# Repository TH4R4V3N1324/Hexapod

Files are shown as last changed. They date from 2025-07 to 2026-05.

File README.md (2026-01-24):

# Hexapod

This repository contains the complete design, control software and documentation for a six-legged walking robot (hexapod). The project combines robotics, kinematics, embedded systems, and motion planning to create a stable and adaptable walking platform.

---

## Table of Contents

- [About](#about)
- [Features](#features)
- [Installation](#installation)
  - [Hexapod](#hexapod)
  - [Receiver & Controller](#receiver--controller)
- [Usage](#usage)

---

## About

This project was developed to address the growing complexity in robotic control systems, where tightly coupled codebases often hinder scalability, debugging, and long-term maintainability. It is designed for developers, researchers, or engineers working with robotic platforms or automation systems who require a clean, extensible control framework that’s easy to understand and build upon.

The primary goal of the project was to emphasize modularity, ensuring that each component of the control software is clearly separated by function and responsibility. This modular design allows developers to quickly comprehend the structure of the system, make targeted changes without unintended side effects, and expand the system by adding new features or improving existing ones without rewriting the entire codebase.

To achieve this, the software is structured around a set of well-defined classes, each serving a distinct role:

- DataPacket Class: Acts as a container for incoming or outgoing data, ensuring that all communication between system components remains consistent, structured, and easily interpretable.

- Calculate Class: Handles all mathematical and logical computations required by the system, such as sensor data interpretation, decision-making algorithms, or movement planning.

- Move Class: Directly interfaces with the actuators or motors, translating high-level commands into specific movement instructions. It abstracts the hardware layer, allowing for easier adaptation across different platforms.

- Animation Class: Manages co-ordination of legs using the various gaits and modes to create walking and animation.

---

## Features

- 3 DOF per leg
- Inverse Kinematic engine for stable gait control
- Multiple gait patterns: tripod, ripple, wave
- Multiple control modes: normal, strafe, tilt
- Real-time control via Pimironi Servo2040
- Wireless control using custom controller and EspNOW protocol
- STL files for 3D-printing mechanical components

---

## Installation

Describe how to get your project running locally. Include prerequisites, dependencies, and step-by-step instructions.

Clone the repository into the desired location using the git bash terminal.
```bash
git clone https://github.com/TH4R4V3N1324/Hexapod.git
```

### Hexapod
Before getting started, make sure you have the following installed:

#### Prerequisites
- [Visual Studio Code](https://code.visualstudio.com/)
- [Pico SDK and cmake toolchain](https://github.com/raspberrypi/pico-sdk)
- [Raspberry Pi Pico VSCode Extension](https://marketplace.visualstudio.com/items?itemName=raspberry-pi.raspberry-pi-pico)

#### Dependencies
- [Pimironi pico sdk](https://github.com/pimoroni/pimoroni-pico.git)

Using the Raspberry Pi Pico VSCode extension, import the Hexapod sub-folder by selecting it in the **Location** tab, enabling **CMake-Tools** and clicking **Import**. 



A selection box will appear at the top of the screen. From the list, choose the appropriate Pico compiler.



Once imported, you can build the project by selecting **Compile Project** from the Pico extension commands. This will generate a .uf2 firmware file inside the build directory.

To flash the firmware to the Pimoroni Servo 2040, put the board into BOOTSEL mode (by holding the BOOT button and pressing RESET), then copy the .uf2 file to the mounted USB storage.

Alternatively, you can enter BOOTSEL mode first, then simply use the **Run Project** command. This will automatically build and flash the firmware to the board, no manual file transfer required.



### Receiver & Controller

#### Prerequisites
- [PlatformIO VSCode Extension](https://marketplace.visualstudio.com/items?itemName=platformio.platformio-ide)

#### Dependencies
- [u8g2 library](https://github.com/olikraus/u8g2.git)

Using the PlatformIO extension in VS Code, select the **Open** option under the **Quick Access** panel to launch the PlatformIO Home page. From there, click **Open Project** and navigate to the appropriate sub-folder to import your project.



To build or upload the project to your ESP32 board, use the **Build** or **Upload** options available under the **Project Tasks** panel in the PlatformIO extension.



---

## Usage

Explain how to use the project. Provide code snippets, screenshots, or examples as helpful.

# Ideas:
# Use ROS2 for control



## Package Structure

### 1. hexapod_description (URDF/Configuration)

- Robot URDF model with leg geometry
- Joint limits and physical parameters
- Launch files for simulation and hardware

### 2. hexapod_hardware_interface (Hardware Layer)

#### Servo Controller Node: Interfaces with PCA9685 or direct PWM

- Subscribes to: /joint_commands (JointState)
- Publishes: /joint_states (JointState with feedback)
- Service: /emergency_stop

#### Sensor Manager Node: Aggregates all sensor data

- Publishes: /imu/data (sensor_msgs/Imu)
- Publishes: /power/status (custom PowerStatus msg)
- Publishes: /leg_contact (custom LegContactArray msg)

### 3. hexapod_kinematics (Computation Layer)

#### IK/FK Solver Node: Your Calculate class logic
- Service: /ik_solve (Vector3 → JointAngles)
- Service: /fk_solve (JointAngles → Vector3)
- Subscribes to: /joint_states (JointState)
- Publishes: /leg_poses (geometry_msgs/PoseArray

### 4. hexapod_gait_controller (Motion Planning)

#### Gait Generator Node: Your Animation/Move logic

- Subscribes to: /cmd_vel (Twist for velocity commands)
- Subscribes to: /gait_mode (String: tripod/ripple/wave)
- Publishes: /leg_trajectories (trajectory_msgs/JointTrajectory)
- Action Server: /execute_gait for complex movements

### 5. hexapod_control (High-Level Control)

#### Behavior Manager Node: State machine (Normal/Strafe/Tilt/Config)

- Subscribes to: /mode_command (custom ModeCommand)
- Subscribes to: /joystick (sensor_msgs/Joy)
- Publishes: /cmd_vel (Twist)
- Service: /set_height, /home_stance

#### Config Manager Node: Servo offset calibration

- Reads/writes to parameter server
- Service: /save_config, /load_config

### 6. hexapod_teleop (User Interface)

#### Joystick Node: Replaces your ESP-NOW controller

- Uses joy_node from ROS2
- Publishes: /joystick (sensor_msgs/Joy)

#### Web Interface Node: Optional dashboard

- rqt plugins or custom web interface
- Monitor battery, IMU, leg contact

# Use Isaac sim for simulation

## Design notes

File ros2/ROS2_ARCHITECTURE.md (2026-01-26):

# Hexapod ROS2 Architecture

This document describes the ROS2 package architecture for the Hexapod robot, designed to work with an ESP32-S3 as a dumb I/O board.

## Table of Contents

- [System Overview](#system-overview)
- [Package Summary](#package-summary)
- [1. hexapod\_msgs](#1-hexapod_msgs)
- [2. hexapod\_description](#2-hexapod_description)
- [3. hexapod\_hardware\_interface](#3-hexapod_hardware_interface)
- [4. hexapod\_gait\_controller](#4-hexapod_gait_controller)
- [5. hexapod\_control](#5-hexapod_control)
- [6. hexapod\_teleop](#6-hexapod_teleop)
- [Data Flow](#data-flow)
- [Topic Reference](#topic-reference)
- [Service Reference](#service-reference)
- [Launch Files](#launch-files)

---

## System Overview

```
┌─────────────────────────────────────────────────────────────────────────────────────┐
│                                    ROS2 System                                       │
│                                                                                      │
│  ┌────────────────┐     ┌────────────────────┐     ┌──────────────────────────────┐ │
│  │ hexapod_teleop │────▶│  hexapod_control   │────▶│  hexapod_gait_controller     │ │
│  │  (user input)  │     │  (behavior/state)  │     │  (motion + IK library)       │ │
│  └────────────────┘     └────────────────────┘     └──────────────┬───────────────┘ │
│                                                                    │                 │
│                                                                    ▼                 │
│  ┌────────────────────────────────────────────────────────────────────────────────┐ │
│  │                      hexapod_hardware_interface                                 │ │
│  │                      (ESP32 serial bridge)                                      │ │
│  └────────────────────────────────────────────────────────────────┬───────────────┘ │
│                                                                    │                 │
│  ┌────────────────┐                                               │                 │
│  │hexapod_descrip-│  URDF/meshes/configs used by all packages     │                 │
│  │tion            │                                               │                 │
│  └────────────────┘                                               │                 │
└───────────────────────────────────────────────────────────────────┼─────────────────┘
                                                                    │ Serial
                                                                    ▼
                                                        ┌───────────────────────┐
                                                        │   ESP32-S3 (Dumb I/O) │
                                                        │   PWM + Sensors +     │
                                                        │   ESP-NOW Relay       │
                                                        └───────────────────────┘
```

### Design Philosophy

- **ESP32 as Dumb I/O**: The ESP32-S3 main board only handles:
  - Receiving joint angles → driving servo PWM
  - Reading sensors → sending to ROS2
  - Relaying ESP-NOW controller data → sending to ROS2
- **ROS2 as Brain**: All intelligence (gait generation, inverse kinematics, behavior control) runs on the companion computer
- **ESP-NOW Controller**: A separate ESP32 controller connects wirelessly to the main board and provides joystick input

---

## Package Summary

| Package | Purpose | Key Components |
|---|---|---|
| `hexapod_msgs` | Custom message/service/action definitions | ControllerInput, PowerStatus, LegContactArray |
| `hexapod_description` | Robot model and configuration | URDF, meshes, parameter files |
| `hexapod_hardware_interface` | ESP32 serial communication | esp32_bridge_node |
| `hexapod_gait_controller` | Motion planning + kinematics | gait_controller_node, kinematics library |
| `hexapod_control` | Behavior and state management | behavior_manager_node, config_manager_node |
| `hexapod_teleop` | Alternative user input methods | joy_teleop_node, keyboard_teleop_node |

---

## 1. hexapod_msgs

**Purpose**: Centralized custom message, service, and action definitions. All other packages depend on this.

### Messages

#### ControllerRaw.msg

Unified controller input that supports multiple input sources (ESP-NOW controller, virtual joystick, keyboard, etc.).

```
# Header with timestamp
builtin_interfaces/Time stamp

# Controller axes (normalized -1.0 to 1.0)
# Standard mapping: [left_x, left_y, right_x, right_y, ...]
# Can be extended for additional axes (triggers, etc.)
float32[] axes

# Discrete command (see Command enum below)
uint16 command_id

# Optional parameters for commands
# e.g., [gait_id], [leg_id, joint_id, offset], [height_mm]
float32[] arguments

# Input source identifier
uint8 source_id

# Source ID constants
uint8 SOURCE_ESPNOW = 0      # Physical ESP-NOW controller
uint8 SOURCE_VIRTUAL_JOY = 1 # Virtual joystick (GUI)
uint8 SOURCE_KEYBOARD = 2    # Keyboard teleop
uint8 SOURCE_GAMEPAD = 3     # USB/Bluetooth gamepad
uint8 SOURCE_AUTONOMY = 4    # Autonomous navigation stack

# Command ID constants (matches embedded Command enum)
uint16 CMD_NONE = 0
uint16 CMD_SET_GAIT = 1
uint16 CMD_SET_MODE = 2
uint16 CMD_SET_CONFIG = 3
uint16 CMD_HOME_STANCE = 4
uint16 CMD_REQUEST_CONFIG = 5
uint16 CMD_SET_HEIGHT = 6
uint16 CMD_EMERGENCY_STOP = 7
```

**Axis Mapping Convention:**

| Index | Axis | Range | Description |
|---|---|---|---|
| 0 | `left_x` | -1.0 to 1.0 | Left stick horizontal (strafe/rotate) |
| 1 | `left_y` | -1.0 to 1.0 | Left stick vertical (forward/back) |
| 2 | `right_x` | -1.0 to 1.0 | Right stick horizontal (rotate/strafe) |
| 3 | `right_y` | -1.0 to 1.0 | Right stick vertical (height adjust) |

**Why this design:**
- **Normalized floats**: Consistent across all input devices (ESP-NOW sends int16 which gets normalized)
- **Extensible axes**: Support for triggers, extra buttons as analog values
- **Source tracking**: Know which controller sent the command for priority/conflict resolution
- **Flexible arguments**: Commands like `CMD_SET_CONFIG` need multiple parameters

#### LegContactArray.msg

Ground contact state for each leg (1-6). Used for adaptive gait and terrain sensing.

```
std_msgs/Header header
bool[6] contacts
```

#### PowerStatus.msg

Power monitoring from INA260. For battery management and safety shutdowns.

```
float32 voltage
float32 current
float32 power
float32 battery_percent
bool low_battery_warning
```

#### HexapodState.msg

Overall robot state broadcast for monitoring/logging.

```
uint8 mode
uint8 gait
float32 body_height
int8 gait_phase
bool is_moving
bool is_stable
```

#### LegCommand.msg

Single leg command with both Cartesian position and joint angles.

```
uint8 leg_id
geometry_msgs/Point position
float64[3] joint_angles
```

### Services

#### SetGait.srv

Change walking gait pattern.

```
# Request
uint8 gait  # 0=tripod, 1=ripple, 2=wave
---
# Response
bool success
string message
```

#### SetMode.srv

Change behavior mode.

```
# Request
uint8 mode  # 0=normal, 1=strafe, 2=tilt, 3=config
---
# Response
bool success
string message
```

#### SetHeight.srv

Adjust body height (clamped to valid range).

```
# Request
float32 height_mm
---
# Response
bool success
float32 actual_height
```

#### GetLegConfig.srv

Retrieve servo calibration offsets.

```
# Request
uint8 leg_id
---
# Response
int16[3] offsets  # coxa, femur, tibia
```

#### SetLegConfig.srv

Set servo calibration offset.

```
# Request
uint8 leg_id
uint8 joint_id
int16 offset
---
# Response
bool success
```

#### SaveConfig.srv

Persist calibration to file.

```
# Request
---
# Response
bool success
string filepath
```

#### EmergencyStop.srv

Disable all servos immediately.

```
# Request
bool stop
---
# Response
bool success
```

### Actions

#### HomeStance.action

Return all legs to home position smoothly.

```
# Goal
---
# Feedback
float32 progress
uint8 current_leg
---
# Result
bool success
float32 duration
```

#### ExecuteAnimation.action

Run predefined animations (startup, shutdown, wave).

```
# Goal
string animation_name
float32 speed
---
# Feedback
float32 progress
uint8 phase
---
# Result
bool success
```

---

## 2. hexapod_description

**Purpose**: Contains the robot's physical description (URDF), visual meshes, and default configuration parameters. This is a **data-only package** with no nodes.

### Directory Structure

```
hexapod_description/
├── urdf/
│   ├── hexapod.urdf.xacro          # Main robot description
│   ├── leg.urdf.xacro              # Single leg macro (reused 6x)
│   └── materials.xacro             # Colors/materials
├── meshes/
│   ├── body.stl
│   ├── coxa.stl
│   ├── femur.stl
│   └── tibia.stl
├── config/
│   ├── hexapod_params.yaml         # Default parameters
│   ├── servo_calibration.yaml      # Joint offsets
│   ├── gait_configs.yaml           # Gait phase patterns
│   └── joint_limits.yaml           # Min/max angles per joint
├── launch/
│   ├── display.launch.py           # RViz visualization
│   ├── hardware.launch.py          # Real robot
│   └── simulation.launch.py        # Gazebo
└── rviz/
    └── hexapod.rviz                # RViz config
```

### Configuration Files

#### hexapod_params.yaml

```yaml
hexapod:
  geometry:
    coxa_length: 50.5      # mm
    femur_length: 90.0     # mm
    tibia_length: 150.35   # mm
    body_radius: 100.0     # mm - distance from center to coxa
  
  legs:
    # Leg mounting angles and mirror flags
    leg_1: { angle: -45.0, mirrored: false, home: [0, 150, -120] }
    leg_2: { angle: 0.0, mirrored: false, home: [0, 150, -120] }
    leg_3: { angle: 45.0, mirrored: false, home: [0, 150, -120] }
    leg_4: { angle: 135.0, mirrored: true, home: [0, 150, -120] }
    leg_5: { angle: 180.0, mirrored: true, home: [0, 150, -120] }
    leg_6: { angle: -135.0, mirrored: true, home: [0, 150, -120] }
  
  motion:
    default_height: 120    # mm
    min_height: 60
    max_height: 180
    step_height: 40        # mm - lift height during swing
    step_resolution: 50    # trajectory points per step
```

#### gait_configs.yaml

```yaml
gaits:
  tripod:
    phase_groups: [[1, 3, 5], [2, 4, 6]]    # Two alternating groups
    duty_cycle: 0.5                          # 50% stance, 50% swing
  ripple:
    phase_groups: [[1, 4], [2, 5], [3, 6]]  # Three groups
    duty_cycle: 0.67
  wave:
    phase_groups: [[1], [2], [3], [4], [5], [6]]  # One leg at a time
    duty_cycle: 0.83
```

### Data Flow

- **To**: All other packages load URDF and configs via `xacro` and ROS2 parameter server
- **Used by**: `robot_state_publisher` for TF, RViz for visualization, Gazebo for simulation

---

## 3. hexapod_hardware_interface

**Purpose**: Bridge between ROS2 and ESP32. Handles serial communication, sensor data ingestion, and joint command transmission. The ESP32 is treated as a dumb I/O device.

### Nodes

#### esp32_bridge_node

Bidirectional serial protocol handler.

**Implementation Details**:
- Uses serial port (e.g., `/dev/ttyUSB0` at 115200 baud)
- Binary protocol with checksums for reliability
- Runs at 100Hz to match ESP32 sensor rate

**Subscribes to**:

| Topic | Type | Source | Purpose |
|---|---|---|---|
| `/hexapod/joint_commands` | `sensor_msgs/JointState` | `gait_controller` | 18 joint angles to send to ESP32 for PWM |

**Publishes**:

| Topic | Type | Destination | Purpose |
|---|---|---|---|
| `/hexapod/controller_input` | `hexapod_msgs/ControllerInput` | `hexapod_control` | Raw joystick data relayed from ESP-NOW controller |
| `/hexapod/joint_states` | `sensor_msgs/JointState` | `robot_state_publisher`, RViz | Current joint positions |
| `/imu/data` | `sensor_msgs/Imu` | `hexapod_control` | Pitch/roll from BMI330 |
| `/hexapod/power` | `hexapod_msgs/PowerStatus` | `hexapod_control`, diagnostics | Voltage/current from INA260 |
| `/hexapod/leg_contacts` | `hexapod_msgs/LegContactArray` | `gait_controller` | Ground contact switches |

**Services**:

| Service | Purpose |
|---|---|
| `/hexapod/emergency_stop` | Sends stop command to ESP32, disables all servo PWM |

**Parameters**:

```yaml
esp32_bridge:
  ros__parameters:
    serial_port: "/dev/ttyUSB0"
    baud_rate: 115200
    publish_rate: 100.0        # Hz
    command_timeout: 0.1       # seconds before servo disable
    reconnect_interval: 2.0    # seconds between reconnection attempts
```

### Serial Protocol

**ROS2 → ESP32 (Joint Commands)**:
```
┌──────┬────────┬────────────────────┬──────────┐
│ 0xAA │ Length │ float32[18] angles │ Checksum │
└──────┴────────┴────────────────────┴──────────┘
```

**ESP32 → ROS2 (Sensor Data)**:
```
┌──────┬────────┬───────────────────────────────────────────────┬──────────┐
│ 0xBB │ Length │ pitch, roll, current, voltage, contacts[6],   │ Checksum │
│      │        │ joy_lx, joy_ly, joy_rx, joy_ry, cmd, args[3]  │          │
└──────┴────────┴───────────────────────────────────────────────┴──────────┘
```

---

## 4. hexapod_gait_controller

**Purpose**: Combines gait pattern generation and inverse kinematics into a single package. The embedded `Animation`, `Move`, and `Calculate` classes are ported here. Kinematics is implemented as a **library within this package** (not a separate node).

### Package Structure

```
hexapod_gait_controller/
├── include/hexapod_gait_controller/
│   ├── kinematics.hpp              # IK/FK calculations
│   ├── trajectory_generator.hpp    # Swing/stance curve generation
│   ├── gait_patterns.hpp           # Tripod/ripple/wave configurations
│   └── leg_controller.hpp          # Per-leg state management
├── src/
│   ├── kinematics.cpp
│   ├── trajectory_generator.cpp
│   ├── gait_patterns.cpp
│   ├── leg_controller.cpp
│   └── gait_controller_node.cpp    # Main node
├── launch/
│   └── gait_controller.launch.py
└── config/
    └── gait_params.yaml
```

### Kinematics Library

Provides IK/FK functions used internally. Not exposed as services (faster, no RPC overhead).

```cpp
namespace hexapod_kinematics {

struct JointAngles {
    double coxa, femur, tibia;
};

struct LegConfig {
    double rotation_angle;    // Leg mounting angle
    bool is_mirrored;         // Left vs right side
    Eigen::Vector3d offset;   // Translation from body center
};

class Kinematics {
public:
    Kinematics(double coxa_len, double femur_len, double tibia_len);
    
    // Inverse kinematics: foot position → joint angles
    // Returns false if position unreachable
    bool solveIK(const Eigen::Vector3d& foot_pos, int leg_id, JointAngles& angles);
    
    // Forward kinematics: joint angles → foot position
    Eigen::Vector3d solveFK(const JointAngles& angles, int leg_id);
    
    // Transform between body frame and leg frame
    Eigen::Vector3d bodyToLegFrame(const Eigen::Vector3d& pos, int leg_id);
    Eigen::Vector3d legToBodyFrame(const Eigen::Vector3d& pos, int leg_id);
    
    void setLegConfig(int leg_id, const LegConfig& config);

private:
    double coxa_length_, femur_length_, tibia_length_;
    std::array<LegConfig, 6> leg_configs_;
};

} // namespace hexapod_kinematics
```

### Nodes

#### gait_controller_node

Main motion planning node. Generates leg trajectories based on velocity commands, runs IK, outputs joint angles at 100Hz.

**Key Responsibilities**:
1. Receive velocity commands (`/cmd_vel`)
2. Generate foot trajectories for current gait pattern
3. Run IK to convert foot positions to joint angles
4. Publish joint commands at high rate

**Subscribes to**:

| Topic | Type | Source | Why Needed |
|---|---|---|---|
| `/hexapod/cmd_vel` | `geometry_msgs/Twist` | `hexapod_control` | Linear.x = forward, linear.y = strafe, angular.z = rotation |
| `/hexapod/leg_contacts` | `hexapod_msgs/LegContactArray` | `hardware_interface` | Detect early ground contact for adaptive stepping |
| `/imu/data` | `sensor_msgs/Imu` | `hardware_interface` | Body orientation for leveling on slopes |

**Publishes**:

| Topic | Type | Destination | Content |
|---|---|---|---|
| `/hexapod/joint_commands` | `sensor_msgs/JointState` | `hardware_interface` | 18 joint angles at 100Hz |
| `/hexapod/leg_poses` | `geometry_msgs/PoseArray` | RViz, debugging | Current foot positions in body frame |
| `/hexapod/state` | `hexapod_msgs/HexapodState` | `hexapod_control`, monitoring | Current gait, phase, stability status |

**Services**:

| Service | Purpose |
|---|---|
| `/hexapod/set_gait` | Switch gait pattern (tripod/ripple/wave) |
| `/hexapod/set_height` | Adjust body height with smooth interpolation |

**Action Servers**:

| Action | Purpose |
|---|---|
| `/hexapod/home_stance` | Return all legs to home position with progress feedback |
| `/hexapod/execute_animation` | Run predefined sequences (startup, shutdown, wave) |

**Parameters**:

```yaml
gait_controller:
  ros__parameters:
    # Geometry (loaded from hexapod_description)
    coxa_length: 50.5
    femur_length: 90.0
    tibia_length: 150.35
    
    # Motion
    control_rate: 100.0         # Hz
    default_gait: "tripod"
    step_height: 40.0           # mm
    trajectory_resolution: 50   # points per swing phase
    
    # Body
    default_height: 120.0       # mm
    
    # Stability
    enable_body_leveling: true
    max_level_correction: 20.0  # mm max leg adjustment
    
    # Adaptive gait
    enable_contact_adaptation: true
```

**Internal State Machine**:

```
┌──────────┐    cmd_vel    ┌──────────┐   all legs    ┌──────────┐
│   IDLE   │──────────────▶│ WALKING  │───grounded───▶│   IDLE   │
└──────────┘   (non-zero)  └────┬─────┘   (zero vel)  └──────────┘
      │                         │
      │                         │ home_stance action
      ▼                         ▼
┌──────────┐              ┌──────────┐
│ STARTUP  │              │  HOMING  │
└──────────┘              └──────────┘
```

---

## 5. hexapod_control

**Purpose**: High-level behavior control. Manages operating modes (normal/strafe/tilt/config), interprets controller input, and coordinates system-wide state. This is the embedded `StateFSM` and `CommandFSM` logic.

### Nodes

#### behavior_manager_node

State machine that interprets user input and manages operating modes.

**Subscribes to**:

| Topic | Type | Source | Why Needed |
|---|---|---|---|
| `/hexapod/controller_input` | `hexapod_msgs/ControllerInput` | `hardware_interface` | Raw joystick data from ESP-NOW controller |
| `/hexapod/state` | `hexapod_msgs/HexapodState` | `gait_controller` | Current robot state for decision making |
| `/imu/data` | `sensor_msgs/Imu` | `hardware_interface` | Body orientation for tilt mode |
| `/hexapod/power` | `hexapod_msgs/PowerStatus` | `hardware_interface` | Battery level for warnings/shutdown |

**Publishes**:

| Topic | Type | Destination | Content |
|---|---|---|---|
| `/hexapod/cmd_vel` | `geometry_msgs/Twist` | `gait_controller` | Processed velocity command based on mode |
| `/hexapod/mode` | `std_msgs/UInt8` | Monitoring, UI | Current mode (0-3) |

**Services Called**:

| Service | When Called |
|---|---|
| `/hexapod/set_gait` | When `command == CMD_SET_GAIT` received |
| `/hexapod/set_mode` | When `command == CMD_SET_MODE` received |
| `/hexapod/home_stance` | When `command == CMD_HOME_STANCE` received |
| `/hexapod/emergency_stop` | When battery critical or error detected |

**Mode Behaviors**:

| Mode | Joystick Mapping | Special Behavior |
|---|---|---|
| **NORMAL** | Left stick: forward/rotate, Right stick: height | Standard walking |
| **STRAFE** | Left stick: forward/strafe, Right stick: rotate/height | Omnidirectional movement |
| **TILT** | Left stick: pitch body, Right stick: roll body | IMU-assisted body tilting |
| **CONFIG** | Left stick: select leg/joint, Right stick: adjust offset | Servo calibration mode |

**Command Handling** (from embedded `CommandFSM`):

```cpp
void handleCommand(const ControllerInput& input) {
    switch (input.command) {
        case CMD_SET_GAIT:
            callService("/hexapod/set_gait", input.command_args[0]);
            break;
        case CMD_SET_MODE:
            current_mode_ = input.command_args[0];
            break;
        case CMD_HOME_STANCE:
            callAction("/hexapod/home_stance");
            break;
        case CMD_SET_CONFIG:
            callService("/hexapod/set_leg_config", 
                input.command_args[0],  // leg
                input.command_args[1],  // joint  
                input.command_args[2]); // offset
            break;
    }
}
```

#### config_manager_node

Manages servo calibration offsets. Replaces the embedded `ConfigManager` class.

**Services**:

| Service | Purpose |
|---|---|
| `/hexapod/get_leg_config` | Retrieve offsets for a leg |
| `/hexapod/set_leg_config` | Set offset for a specific joint |
| `/hexapod/save_config` | Write current offsets to YAML file |
| `/hexapod/load_config` | Load offsets from YAML file |

**Publishes**:

| Topic | Type | Purpose |
|---|---|---|
| `/hexapod/joint_offsets` | `sensor_msgs/JointState` | Current calibration offsets |

**Data Storage**:
- Offsets stored in `hexapod_description/config/servo_calibration.yaml`
- Loaded at startup, saved on request

---

## 6. hexapod_teleop

**Purpose**: Alternative input methods beyond the ESP-NOW controller. Useful for development, testing, and when ESP32 controller isn't available.

### Nodes

#### joy_teleop_node

Convert standard gamepad to controller input format.

**Subscribes to**:

| Topic | Type | Source |
|---|---|---|
| `/joy` | `sensor_msgs/Joy` | `joy` package (gamepad driver) |

**Publishes**:

| Topic | Type | Purpose |
|---|---|---|
| `/hexapod/cmd_vel` | `geometry_msgs/Twist` | Direct velocity commands |

**Parameters**:

```yaml
joy_teleop:
  ros__parameters:
    # Axis mappings (for Xbox controller)
    axis_linear_x: 1      # Left stick Y
    axis_linear_y: 0      # Left stick X
    axis_angular_z: 3     # Right stick X
    axis_height: 4        # Right stick Y
    
    # Button mappings
    btn_gait_cycle: 0     # A button
    btn_mode_cycle: 1     # B button
    btn_home: 2           # X button
    btn_emergency: 7      # Start button
    
    # Scaling
    max_linear: 100.0     # mm/s
    max_angular: 0.5      # rad/s
    deadzone: 0.1
```

#### keyboard_teleop_node (Optional)

Simple keyboard control for testing.

**Key Mappings**:
- WASD: Move forward/strafe
- QE: Rotate
- RF: Height up/down
- 1/2/3: Select gait
- Space: Home stance

---

## Data Flow

```
┌─────────────────────────────────────────────────────────────────────────────────────┐
│                                                                                      │
│   ESP32 Controller ──ESP-NOW──▶ ESP32 Main Board                                    │
│                                      │                                               │
│                                      │ Serial @ 100Hz                               │
│                                      ▼                                               │
│   ┌─────────────────────────────────────────────────────────────────────────────┐   │
│   │                        esp32_bridge_node                                     │   │
│   │  OUT: /controller_input, /imu/data, /power, /leg_contacts, /joint_states    │   │
│   │  IN:  /joint_commands                                                        │   │
│   └───────┬────────────┬────────────┬────────────┬───────────────────────────────┘   │
│           │            │            │            │                                   │
│           ▼            ▼            ▼            │                                   │
│   /controller_input  /imu/data   /power     /leg_contacts                           │
│           │            │   │        │            │                                   │
│           ▼            │   │        ▼            │                                   │
│   ┌──────────────────┐ │   │  ┌──────────┐       │                                   │
│   │behavior_manager  │◀┘   │  │Diagnostics│      │                                   │
│   │                  │     │  │Low battery│      │                                   │
│   │ Mode: NORMAL     │     │  └──────────┘       │                                   │
│   │ CMD handling     │     │                     │                                   │
│   └────────┬─────────┘     │                     │                                   │
│            │               │                     │                                   │
│            ▼               │                     │                                   │
│      /cmd_vel              │                     │                                   │
│            │               │                     │                                   │
│            ▼               ▼                     ▼                                   │
│   ┌────────────────────────────────────────────────────────────────────────────┐    │
│   │                      gait_controller_node                                   │    │
│   │                                                                             │    │
│   │  ┌──────────────┐   ┌──────────────┐   ┌─────────────────┐                 │    │
│   │  │Gait Generator│──▶│Trajectory Gen│──▶│IK (kinematics)  │                 │    │
│   │  │tripod/ripple │   │swing/stance  │   │pos → angles     │                 │    │
│   │  └──────────────┘   └──────────────┘   └────────┬────────┘                 │    │
│   │                                                  │                          │    │
│   └──────────────────────────────────────────────────┼──────────────────────────┘    │
│                                                      │                               │
│                                                      ▼                               │
│                                              /joint_commands                         │
│                                                      │                               │
│                                                      ▼                               │
│   ┌─────────────────────────────────────────────────────────────────────────────┐   │
│   │                        esp32_bridge_node                                     │   │
│   └─────────────────────────────────────────────────────────────────────────────┘   │
│                                      │                                               │
│                                      │ Serial                                        │
│                                      ▼                                               │
│                              ESP32 Main Board                                        │
│                                      │                                               │
│                                      ▼ PWM                                           │
│                                  [18 Servos]                                         │
│                                                                                      │
└─────────────────────────────────────────────────────────────────────────────────────┘
```

---

## Topic Reference

| Topic | Type | Publisher | Subscriber(s) | Rate |
|---|---|---|---|---|
| `/hexapod/controller_input` | `ControllerInput` | `esp32_bridge` | `behavior_manager` | 50Hz |
| `/hexapod/joint_commands` | `JointState` | `gait_controller` | `esp32_bridge` | 100Hz |
| `/hexapod/joint_states` | `JointState` | `esp32_bridge` | `robot_state_publisher` | 100Hz |
| `/hexapod/cmd_vel` | `Twist` | `behavior_manager` | `gait_controller` | 50Hz |
| `/hexapod/leg_contacts` | `LegContactArray` | `esp32_bridge` | `gait_controller` | 100Hz |
| `/hexapod/power` | `PowerStatus` | `esp32_bridge` | `behavior_manager` | 10Hz |
| `/hexapod/state` | `HexapodState` | `gait_controller` | `behavior_manager` | 20Hz |
| `/hexapod/leg_poses` | `PoseArray` | `gait_controller` | RViz | 20Hz |
| `/hexapod/mode` | `UInt8` | `behavior_manager` | Monitoring | On change |
| `/imu/data` | `Imu` | `esp32_bridge` | `gait_controller`, `behavior_manager` | 100Hz |
| `/tf` | `TFMessage` | `robot_state_publisher` | RViz, others | 100Hz |

---

## Service Reference

| Service | Package | Purpose |
|---|---|---|
| `/hexapod/set_gait` | `gait_controller` | Change gait pattern |
| `/hexapod/set_mode` | `control` | Change behavior mode |
| `/hexapod/set_height` | `gait_controller` | Adjust body height |
| `/hexapod/get_leg_config` | `control` | Get servo offsets |
| `/hexapod/set_leg_config` | `control` | Set servo offset |
| `/hexapod/save_config` | `control` | Save calibration |
| `/hexapod/load_config` | `control` | Load calibration |
| `/hexapod/emergency_stop` | `hardware_interface` | Disable servos |

---

## Launch Files

### hexapod_bringup/launch/hexapod.launch.py

```python
from launch import LaunchDescription
from launch_ros.actions import Node
from launch.actions import IncludeLaunchDescription

def generate_launch_description():
    return LaunchDescription([
        # Robot description & TF
        IncludeLaunchDescription(
            'hexapod_description/launch/robot_state_publisher.launch.py'
        ),
        
        # Hardware interface
        Node(
            package='hexapod_hardware_interface',
            executable='esp32_bridge_node',
            parameters=['config/esp32_params.yaml']
        ),
        
        # Gait controller (includes kinematics library)
        Node(
            package='hexapod_gait_controller',
            executable='gait_controller_node',
            parameters=[
                'config/gait_params.yaml',
                'config/hexapod_params.yaml'
            ]
        ),
        
        # Behavior manager
        Node(
            package='hexapod_control',
            executable='behavior_manager_node',
            parameters=['config/control_params.yaml']
        ),
        
        # Config manager
        Node(
            package='hexapod_control',
            executable='config_manager_node',
            parameters=['config/servo_calibration.yaml']
        ),
    ])
```

---

## Mapping: Embedded Code → ROS2

| Embedded Component | ROS2 Equivalent |
|---|---|
| `ControlPacket` | `/hexapod/controller_input` topic |
| `HexPacket` | `/hexapod/state` topic |
| `CommandFSM()` | Service handlers in `behavior_manager_node` |
| `StateFSM()` | Main loop in `behavior_manager_node` |
| `Animation` class | `gait_controller_node` |
| `Move` class | `gait_controller_node` + kinematics library |
| `Calculate` class | `hexapod_kinematics` library |
| `Servo` class | `esp32_bridge_node` → ESP32 |
| `ConfigManager` | `config_manager_node` |
| `IMUSensor` | `esp32_bridge_node` → `/imu/data` |
| `CurrentSensor` | `esp32_bridge_node` → `/hexapod/power` |
| `LegContactSensor` | `esp32_bridge_node` → `/hexapod/leg_contacts` |
| ESP-NOW comm | Relayed through ESP32 to `/hexapod/controller_input` |

---

## ESP32 Firmware (Simplified)

With ROS2 handling all intelligence, the ESP32 code becomes minimal:

```cpp
// main.cpp - Dumb I/O only
void setup() {
    Serial.begin(115200);
    servoController.init();
    imu.init();
    currentSensor.init();
    legContact.init();
    initEspNow();
}

void loop() {
    // 1. Receive joint angles from ROS2 → set servos
    if (receiveJointAngles(angles)) {
        for (int i = 0; i < 18; i++) {
            servoController.setAngle(i, angles[i]);
        }
    }
    
    // 2. Send sensor data to ROS2
    sendSensorData(
        imu.getPitch(), imu.getRoll(),
        currentSensor.readCurrent(),
        currentSensor.readVoltage(),
        legContacts
    );
    
    // 3. Relay ESP-NOW controller input to ROS2
    if (controllerDataReceived) {
        sendControllerInput(controlPacket);
    }
}
```

**Removed from ESP32**: `Animation`, `Move`, `Calculate`, `StateFSM`, `CommandFSM` — all moved to ROS2.

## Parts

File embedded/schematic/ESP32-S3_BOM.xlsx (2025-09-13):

Quantity | Item | Manufacturer | Part Number | Link | Interesting items | datasheet | comment
1 | ESP32-s3 | Espressif Systems | ESP32-S3-MINI-1U-N8 | Mouser No: 356-ESP32S3MINI1UN8 (https://www.mouser.co.uk/ProductDetail/Espressif-Systems/ESP32-S3-MINI-1U-N8?qs=IPgv5n7u5QZ2yjt9dMz22g%3D%3D) | 5V 20A DC-DC converter (https://www.mouser.co.uk/ProductDetail/Murata-Power-Solutions/OKL2-T-20-W12N2-C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) | datasheet (https://www.murata.com/products/productdata/8807038353438/okl2-t20-w12.pdf?1583754815000) | Could use this instead of custom voltage reg circuit
1 | Current sensor | Texas Instruments | INA260AIPWR | Mouser No: 595-INA260AIPWR (https://www.mouser.co.uk/ProductDetail/Texas-Instruments/INA260AIPWR?qs=vcbl%252BK4rRldNzXQDYx03SQ%3D%3D)
1 | IMU | Bosch Sensortec | BMI330 | Mouser No: 262-BMI330 (https://www.mouser.co.uk/ProductDetail/Bosch-Sensortec/BMI330?qs=CoAU%2FpHVZXxs%2FTDo6zopZQ%3D%3D)
1 | Battery Monitor | Texas Instruments | BQ7692006PWR | Mouser No: 595-BQ7692006PWR (https://www.mouser.co.uk/ProductDetail/Texas-Instruments/BQ7692006PWR?qs=%2Fd%252BFzHvH4c1cik2Itzn1yQ%3D%3D)
1 | Battery Charger | Texas Instruments | BQ24610RGER | Mouser No: 595-BQ24610RGER (https://www.mouser.co.uk/ProductDetail/Texas-Instruments/BQ24610RGER?qs=%2Fqzd9s%252BcLd67%2Fekl7yXWkA%3D%3D)
1 | 5V regulator IC | Analog Devices | LTM4620AEV#PBF | Mouser No: 584-LTM4620AEV#PBF (https://www.mouser.co.uk/ProductDetail/Analog-Devices/LTM4620AEVPBF?qs=hVkxg5c3xu%252B4aA%252Bft3KM%2FA%3D%3D)

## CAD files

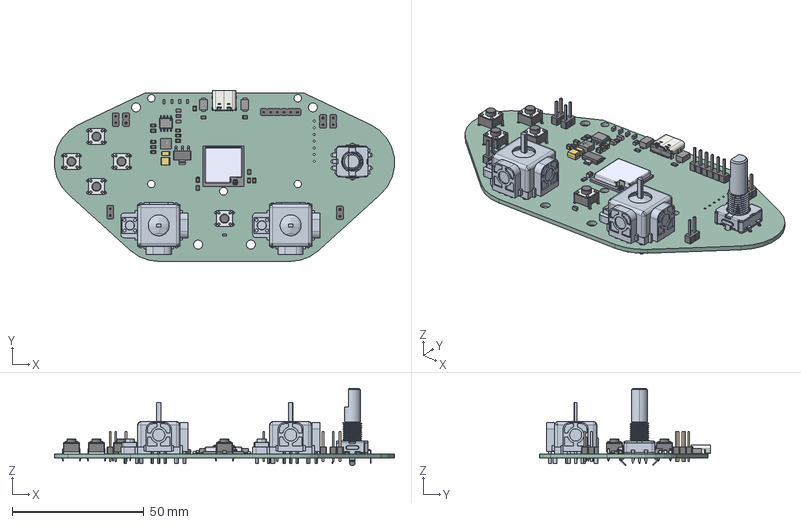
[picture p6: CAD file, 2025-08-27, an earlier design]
controller/controller/schematic/hexControllerV3/hexControllerV3.step
128.8 x 64.7 x 29.2 mm
TS6-THT_H-4.3.step x 5
Pins x 7
ESP32-S2-MINI-2U-N4_ESP32-S2-MINI-2U-N4
Antenna_Antenna
C_0805_2012Metric x 2
PinHeader_1x02_P2.54mm_Vertical x 6
SOT-223
hexControllerV3 1.10.1 x 2
FilletPin1 x 2
FilletPin2 x 2
R_0805_2012Metric x 8
hexControllerV3 1.21.1
XAL4020-102MEC
PinsArrayLR
ThermalPad
PinHeader_1x06_P2.54mm_Vertical
USB_C_Receptacle_GCT_USB4105-xx-A_16P_TopMnt_Horizontal
hexControllerV3_PCB

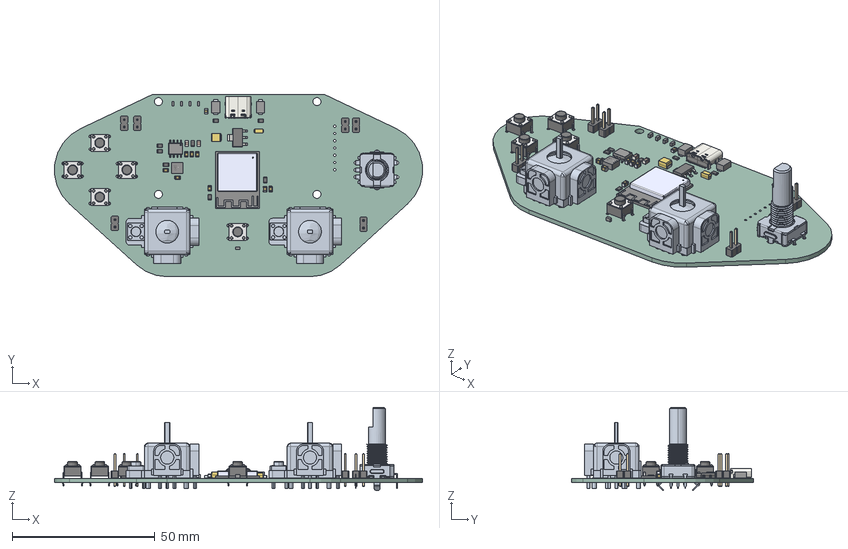
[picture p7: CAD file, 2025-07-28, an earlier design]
CustomController/Design/schematic/hexControllerV2/hexControllerV2.step
128.8 x 63.9 x 29.2 mm
TS6-THT_H-4.3.step x 5
Pins x 7
ESP32-S2-MINI-1-N4R2
C_0805_2012Metric x 2
PinHeader_1x02_P2.54mm_Vertical x 6
SOT-223
hexControllerV2 1.10.1 x 2
FilletPin1 x 2
FilletPin2 x 2
R_0805_2012Metric x 8
hexControllerV2 1.21.1
XAL4020-102MEC
PinsArrayLR
ThermalPad
USB_C_Receptacle_GCT_USB4105-xx-A_16P_TopMnt_Horizontal
hexControllerV2_PCB

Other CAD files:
controller/controller/schematic/hexControllerV3/hexControllerV2.step
CustomController/Design/schematic/hexControllerV2/hexControllerV2.stl

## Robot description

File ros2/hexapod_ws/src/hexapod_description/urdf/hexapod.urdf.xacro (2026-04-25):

<robot xmlns:xacro="http://ros.org/wiki/xacro" name="hexapod">

  <xacro:arg name="controllers_file" default=""/>

  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
  <xacro:property name="coxa_length" value="0.0375"/>
  <xacro:property name="femur_length" value="0.1"/>
  <xacro:property name="tibia_length" value="0.15"/>
  <xacro:property name="femur_z_offset" value="0.0106"/>

  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
  <link name="base_link">
    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
    <inertial>
      <mass value="1.0"/>
      <origin xyz="0 0 0"/>
      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
    </inertial>
  </link>

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
<xacro:macro name="leg" params="name x_offset y_offset yaw colour">

  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
  <link name="${name}_coxa">
    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
    <inertial>
      <mass value="0.1"/>
      <origin xyz="0 0 0"/>
      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
    </inertial>
  </link>

  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
  <link name="${name}_femur">
    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
    <inertial>
      <mass value="0.05"/>
      <origin xyz="0 0 0"/>
      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
    </inertial>
  </link>

  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
  <link name="${name}_tibia">
    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
    <inertial>
      <mass value="0.05"/>
      <origin xyz="0 0 0"/>
      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
    </inertial>
  </link>

  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
  <joint name="${name}_coxa_joint" type="revolute">
    <parent link="base_link"/>
    <child link="${name}_coxa"/>
    <origin xyz="${x_offset} ${y_offset} 0" rpy="0 0 ${yaw}"/>
    <axis xyz="0 0 1"/>
    <limit lower="-1.57" upper="1.57" effort="1" velocity="1"/>
  </joint>

  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
  <joint name="${name}_femur_joint" type="revolute">
    <parent link="${name}_coxa"/>
    <child link="${name}_femur"/>
    <origin xyz="${coxa_length} 0 ${femur_z_offset}" rpy="0 0 0"/>
    <axis xyz="0 1 0"/>
    <limit lower="-1.57" upper="1.57" effort="1" velocity="1"/>
  </joint>

  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
  <joint name="${name}_tibia_joint" type="revolute">
    <parent link="${name}_femur"/>
    <child link="${name}_tibia"/>
    <origin xyz="${femur_length} 0 0" rpy="0 1.5708 0"/> 
    <axis xyz="0 1 0"/>
    <limit lower="-1.57" upper="1.57" effort="1" velocity="1"/>
  </joint>

  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

</xacro:macro>

  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
  <xacro:leg name="leg1" x_offset="0.06733" y_offset="0.0846" yaw="0.5236" colour="red"/>

  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
  <xacro:leg name="leg2" x_offset="0.090" y_offset="0" yaw="0" colour="green"/>

  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
  <xacro:leg name="leg3" x_offset="0.06733" y_offset="-0.0846" yaw="-0.5236" colour="blue"/>

  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
  <xacro:leg name="leg4" x_offset="-0.06733" y_offset="-0.0846" yaw="-2.61799" colour="yellow"/>

  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
  <xacro:leg name="leg5" x_offset="-0.090" y_offset="0" yaw="-3.14159" colour="cyan"/>

  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
  <xacro:leg name="leg6" x_offset="-0.06733" y_offset="0.0846" yaw="2.61799" colour="magenta"/>

  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
  <xacro:macro name="ros2_control_joint" params="joint_name">
    <joint name="${joint_name}">
      <command_interface name="position"/>
      <state_interface name="position"/>
      <state_interface name="velocity"/>
    </joint>
  </xacro:macro>

  <ros2_control name="HexapodHardware" type="system">
    <hardware>
      <plugin>gz_ros2_control/GazeboSimSystem</plugin>
    </hardware>
    <xacro:ros2_control_joint joint_name="leg1_coxa_joint"/>
    <xacro:ros2_control_joint joint_name="leg1_femur_joint"/>
    <xacro:ros2_control_joint joint_name="leg1_tibia_joint"/>
    <xacro:ros2_control_joint joint_name="leg2_coxa_joint"/>
    <xacro:ros2_control_joint joint_name="leg2_femur_joint"/>
    <xacro:ros2_control_joint joint_name="leg2_tibia_joint"/>
    <xacro:ros2_control_joint joint_name="leg3_coxa_joint"/>
    <xacro:ros2_control_joint joint_name="leg3_femur_joint"/>
    <xacro:ros2_control_joint joint_name="leg3_tibia_joint"/>
    <xacro:ros2_control_joint joint_name="leg4_coxa_joint"/>
    <xacro:ros2_control_joint joint_name="leg4_femur_joint"/>
    <xacro:ros2_control_joint joint_name="leg4_tibia_joint"/>
    <xacro:ros2_control_joint joint_name="leg5_coxa_joint"/>
    <xacro:ros2_control_joint joint_name="leg5_femur_joint"/>
    <xacro:ros2_control_joint joint_name="leg5_tibia_joint"/>
    <xacro:ros2_control_joint joint_name="leg6_coxa_joint"/>
    <xacro:ros2_control_joint joint_name="leg6_femur_joint"/>
    <xacro:ros2_control_joint joint_name="leg6_tibia_joint"/>
  </ros2_control>

  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

</robot>

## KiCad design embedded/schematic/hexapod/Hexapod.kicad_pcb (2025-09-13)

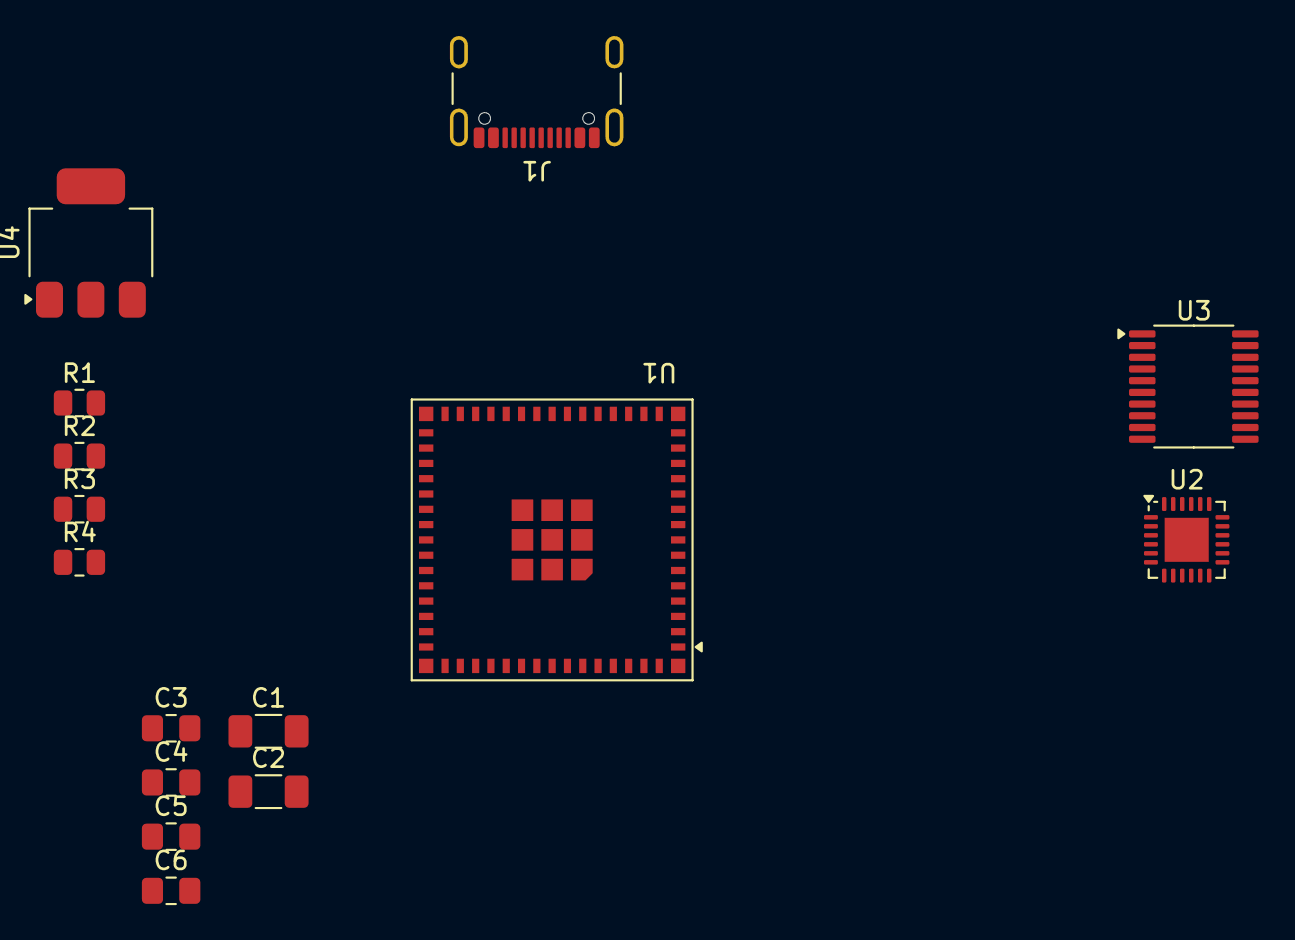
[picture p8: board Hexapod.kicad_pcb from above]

Board: 2 copper layers, 15 parts (0 on the bottom side), 10 nets, no tracks yet.

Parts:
C1: 22uF; C_1206_3216Metric_Pad1.33x1.80mm_HandSolder
C2: 10uF; C_1206_3216Metric_Pad1.33x1.80mm_HandSolder
C3: 22uF; C_0805_2012Metric_Pad1.18x1.45mm_HandSolder
C4, C6: 100nF; C_0805_2012Metric_Pad1.18x1.45mm_HandSolder
C5: 1uF; C_0805_2012Metric_Pad1.18x1.45mm_HandSolder
J1: USB_C_Receptacle_USB2.0_16P; USB_C_Receptacle_GCT_USB4105-xx-A_16P_TopMnt_Horizontal
R1: 10k; R_0805_2012Metric
R2: 100R; R_0805_2012Metric
R3, R4: 5.1k; R_0805_2012Metric
U1: ESP32-S3-MINI-1U; ESP32-S2-MINI-1U
U2: BQ24610; VQFN-24-1EP_4x4mm_P0.5mm_EP2.45x2.45mm
U3: BQ76920PW; TSSOP-20_4.4x6.5mm_P0.65mm
U4: AMS1117-3.3; SOT-223-3_TabPin2

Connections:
+3V3: C1.1 (+), C3.1, C4.1, R1.1, U1.3 (3V3), U2.24 (VCC), U3.9 (REGSRC), U4.2 (VO)
+5V: C2.1 (+), U4.3 (VI)
+5V USB: J1.A4 (VBUS), J1.A9 (VBUS), J1.B4 (VBUS), J1.B9 (VBUS)
BOOT: R2.1, U1.4 (IO0)
D+: J1.A6 (D+), J1.B6 (D+), U1.24 (USB_D+)
D-: J1.A7 (D-), J1.B7 (D-), U1.23 (USB_D-)
EN: C5.1, C6.1, R1.2, U1.45 (EN)
GND: C1.2 (-), C2.2 (-), C3.2, C4.2, C5.2, C6.2, J1.A1 (GND), J1.A12 (GND), J1.B1 (GND), J1.B12 (GND), J1.S1 (SHIELD), R3.2, R4.2, U1.1 (GND), U1.2 (GND), U1.42 (GND), U1.43 (GND), U1.46 (GND), U1.47 (GND), U1.48 (GND), U1.49 (GND), U1.50 (GND), U1.51 (GND), U1.52 (GND), U1.53 (GND), U1.54 (GND), U1.55 (GND), U1.56 (GND), U1.57 (GND), U1.58 (GND), U1.59 (GND), U1.60 (GND), U1.61 (GND), U1.62 (GND), U1.63 (GND), U1.64 (GND), U1.65 (GND), U2.17 (GND), U2.25 (GND), U3.3 (VSS), U4.1 (GND)
unnamed: J1.A5 (CC1), R3.1
unnamed: J1.B5 (CC2), R4.1

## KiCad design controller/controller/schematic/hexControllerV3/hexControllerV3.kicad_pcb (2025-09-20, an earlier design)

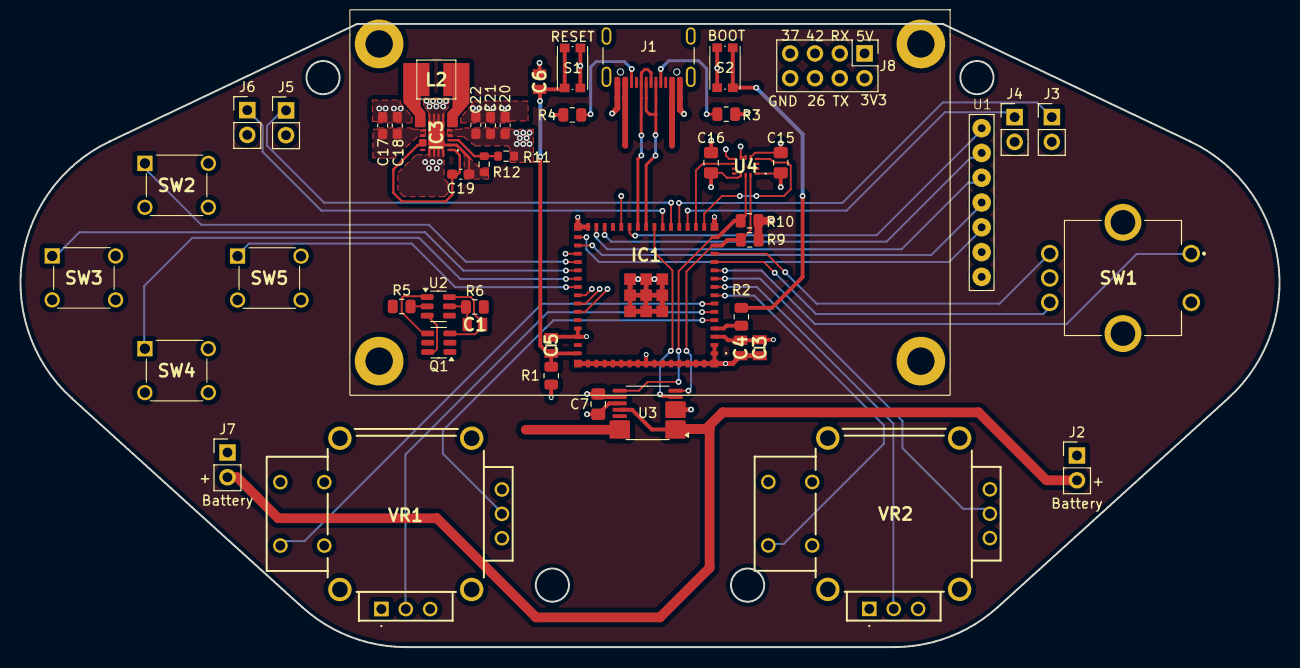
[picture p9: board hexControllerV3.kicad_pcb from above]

Board: 4 copper layers, 129.0 x 63.9 mm, 49 parts (0 on the bottom side), 54 nets.

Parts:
C1, C4, C6: 100nF; CAPC2012X95N
C3: 22uF; CAPC2012X140N
C5: 1uF; CAPC2012X135N
C7, C15, C16: 100nF; C_0805_2012Metric_Pad1.18x1.45mm_HandSolder
C17, C18: 10uF; C_0603_1608Metric_Pad1.08x0.95mm_HandSolder
C19: 100nF; C_0603_1608Metric_Pad1.08x0.95mm_HandSolder
C20, C21, C22: 22uF; C_0603_1608Metric_Pad1.08x0.95mm_HandSolder
IC1: ESP32-S2-MINI-1-N4R2; ESP32S2MINI1N4R2
IC3: TPS63020DSJR
J1: USB_C_Receptacle_USB2.0_16P; USB_C_Receptacle_GCT_USB4105-xx-A_16P_TopMnt_Horizontal
J2, J7: Battery; PinHeader_1x02_P2.54mm_Vertical
J3: Switch1; PinHeader_1x02_P2.54mm_Vertical
J4: Switch2; PinHeader_1x02_P2.54mm_Vertical
J5: Switch3; PinHeader_1x02_P2.54mm_Vertical
J6: Switch4; PinHeader_1x02_P2.54mm_Vertical
J8: Conn_01x06; PinHeader_2x04_P2.54mm_Vertical
L2: 1.5uH; XAL40XX
Q1: DMG9926UDM; SOT-23-6
R1: 10k; R_0805_2012Metric
R2, R6: 100R; R_0805_2012Metric
R3, R4: 5.1k; R_0805_2012Metric
R5: 1k; R_0805_2012Metric
R9, R10: 4.7K; R_0805_2012Metric
R11: 1M; R_0603_1608Metric
R12: 180K; R_0603_1608Metric
S1, S2: KMR731NG; SW_Push_1P1T_NO_CK_KMR2
SW1: RotaryEncoder_Switch; PEC11L4120FS0020
SW2, SW3, SW4, SW5: SW_DIP_x01; DTS62NV
U1: WaveShare_2.42inch_SSD1309_OLED
U2: DW01A; SOT-23-6
U3: INA260; TSSOP-16_4.4x5mm_P0.65mm
U4: BMI330
VR1, VR2: COM-16273; COM16273

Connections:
+3V3: C3.1, C4.1, C7.1, C15.2, C16.2, C20.1, C21.1, C22.1, IC1.3 (3V3), IC3.4 (VOUT_1), IC3.5 (VOUT_2), J8.2, R1.1, R9.1, R10.2, R11.1, U3.10 (VS), U4.5 (VDDIO), U4.8 (VDD), U4.12 (CSB), VR1.1 (CCW1), VR1.4 (CCW2), VR2.1 (CCW1), VR2.4 (CCW2)
+5V: C17.1, C18.1, IC3.10 (VIN_1), IC3.11 (VIN_2), J8.1, U1.7 (VCC)
+5V USB: J1.A4 (VBUS), J1.A9 (VBUS), J1.B4 (VBUS), J1.B9 (VBUS)
BAT+: J2.2, J7.2, R6.2, U3.1 (IN+), U3.2 (IN+), U3.3 (IN+), U3.12 (VBUS)
BMI330_INT1: IC1.16 (IO12), U4.4 (INT1)
BMI330_INT2: IC1.17 (IO13), U4.9 (INT2)
BOOT: IC1.4 (IO0), R2.1
CLK: IC1.32 (IO36), U1.4 (CLK/SCL)
CS: IC1.29 (IO34), U1.3 (CS)
D+: IC1.24 (IO20), J1.A6 (D+), J1.B6 (D+)
D-: IC1.23 (IO19), J1.A7 (D-), J1.B7 (D-)
DC: IC1.28 (IO33), U1.2 (DC/ADDR)
DIN: IC1.31 (IO35), U1.5 (DIN/SDA)
EN: C5.1, C6.1, IC1.45 (EN), R1.2, S1.1 (A)
EncoderA: IC1.13 (IO9), SW1.A
EncoderB: IC1.12 (IO8), SW1.B
EncoderSW: IC1.11 (IO7), SW1.S1
GND: C3.2, C4.2, C5.2, C6.2, C7.2, C15.1, C16.1, C17.2, C18.2, C19.2, C20.2, C21.2, C22.2, IC1.1 (GND_1), IC1.2 (GND_2), IC1.30 (GND_3), IC1.42 (GND_4), IC1.43 (GND_5), IC1.46 (GND_6), IC1.47 (GND_7), IC1.48 (GND_8), IC1.49 (GND_9), IC1.50 (GND_10), IC1.51 (GND_11), IC1.52 (GND_12), IC1.53 (GND_13), IC1.54 (GND_14), IC1.55 (GND_15), IC1.56 (GND_16), IC1.57 (GND_17), IC1.58 (GND_18), IC1.59 (GND_19), IC1.60 (GND_20), IC1.61 (GND_21), IC1.62 (GND_22), IC1.63 (GND_23), IC1.64 (GND_24), IC1.65 (GND_25), IC1.66 (GND_26), IC1.67 (GND_27), IC1.68 (GND_28), IC1.69 (GND_29), IC1.70 (GND_30), IC1.71 (GND_31), IC1.72 (GND_32), IC1.73 (GND_33), IC3.2 (GND), IC3.15 (PGND_1), IC3.16 (PGND_2), IC3.17 (PGND_3), IC3.18 (PGND_4), IC3.19 (PGND_5), IC3.20 (PGND_6), IC3.21 (PGND_7), IC3.22 (PGND_8), IC3.23 (PGND_9), J1.A1 (GND), J1.A12 (GND), J1.B1 (GND), J1.B12 (GND), J1.S1 (SHIELD), J3.2, J4.2, J5.2, J6.2, J8.8, Q1.1 (D1), R3.2, R4.2, R5.1, R12.2, S1.2 (B), S2.2 (B), SW1.C, SW1.S2, SW2.3 (K), SW2.4 (A), SW3.3 (K), SW3.4 (A), SW4.3 (K), SW4.4 (A), SW5.3 (K), SW5.4 (A), U1.6 (GND), U3.4 (A1), U3.5 (A0), U3.6 (GND), U3.11 (GND), U4.1 (SDO), U4.6 (GNDIO), U4.7 (GND), VR1.3 (CW1), VR1.6 (CW2), VR1.S2 (COM_2), VR2.3 (CW1), VR2.6 (CW2), VR2.S2 (COM_2)
GPIO26: IC1.26 (IO26), J8.6
GPIO37: IC1.33 (IO37), J8.7
GPIO42: IC1.38 (IO42), J8.5
INA260_INT: IC1.22 (IO18), U3.7 (ALERT)
INA260_OUT: U3.14 (IN-), U3.15 (IN-), U3.16 (IN-)
Joy1Button: IC1.7 (IO3), VR1.S1 (COM_1)
Joy1X: IC1.6 (IO2), VR1.2 (WIPER1)
Joy1Y: IC1.5 (IO1), VR1.5 (WIPER2)
Joy2Button: IC1.8 (IO4), VR2.S1 (COM_1)
Joy2X: IC1.9 (IO5), VR2.2 (WIPER1)
Joy2Y: IC1.10 (IO6), VR2.5 (WIPER2)
unnamed: C19.1, IC3.1 (VINA), IC3.12 (EN), IC3.13 (PS/SYNC)
unnamed: IC3.3 (FB), R11.2, R12.1
unnamed: IC3.8 (L1_1), IC3.9 (L1_2), L2.1
unnamed: IC3.6 (L2_1), IC3.7 (L2_2), L2.2
unnamed: J1.A5 (CC1), R3.1
unnamed: J1.B5 (CC2), R4.1
unnamed: C1.1, J2.1, J7.1, Q1.3 (S2), U2.6 (GND)
unnamed: Q1.6 (G1), U2.3 (OC)
unnamed: Q1.4 (G2), U2.1 (OD)
unnamed: R2.2, S2.1 (A)
unnamed: R5.2, U2.2 (CS)
unnamed: C1.2, R6.1, U2.5 (VCC)
RST: IC1.25 (IO21), U1.1 (RST)
RX: IC1.40 (RXD0), J8.3
SCL: IC1.15 (IO11), R10.1, U3.9 (SCL), U4.13 (SCX)
SDA: IC1.14 (IO10), R9.2, U3.8 (SDA), U4.14 (SDX)
Switch1: IC1.19 (IO15), J3.1
Switch2: IC1.18 (IO14), J4.1
Switch3: IC1.20 (IO16), J5.1
Switch4: IC1.21 (IO17), J6.1
TX: IC1.39 (TXD0), J8.4
button1: IC1.34 (IO38), SW2.1
button2: IC1.35 (IO39), SW3.1
button3: IC1.36 (IO40), SW4.1
button4: IC1.37 (IO41), SW5.1

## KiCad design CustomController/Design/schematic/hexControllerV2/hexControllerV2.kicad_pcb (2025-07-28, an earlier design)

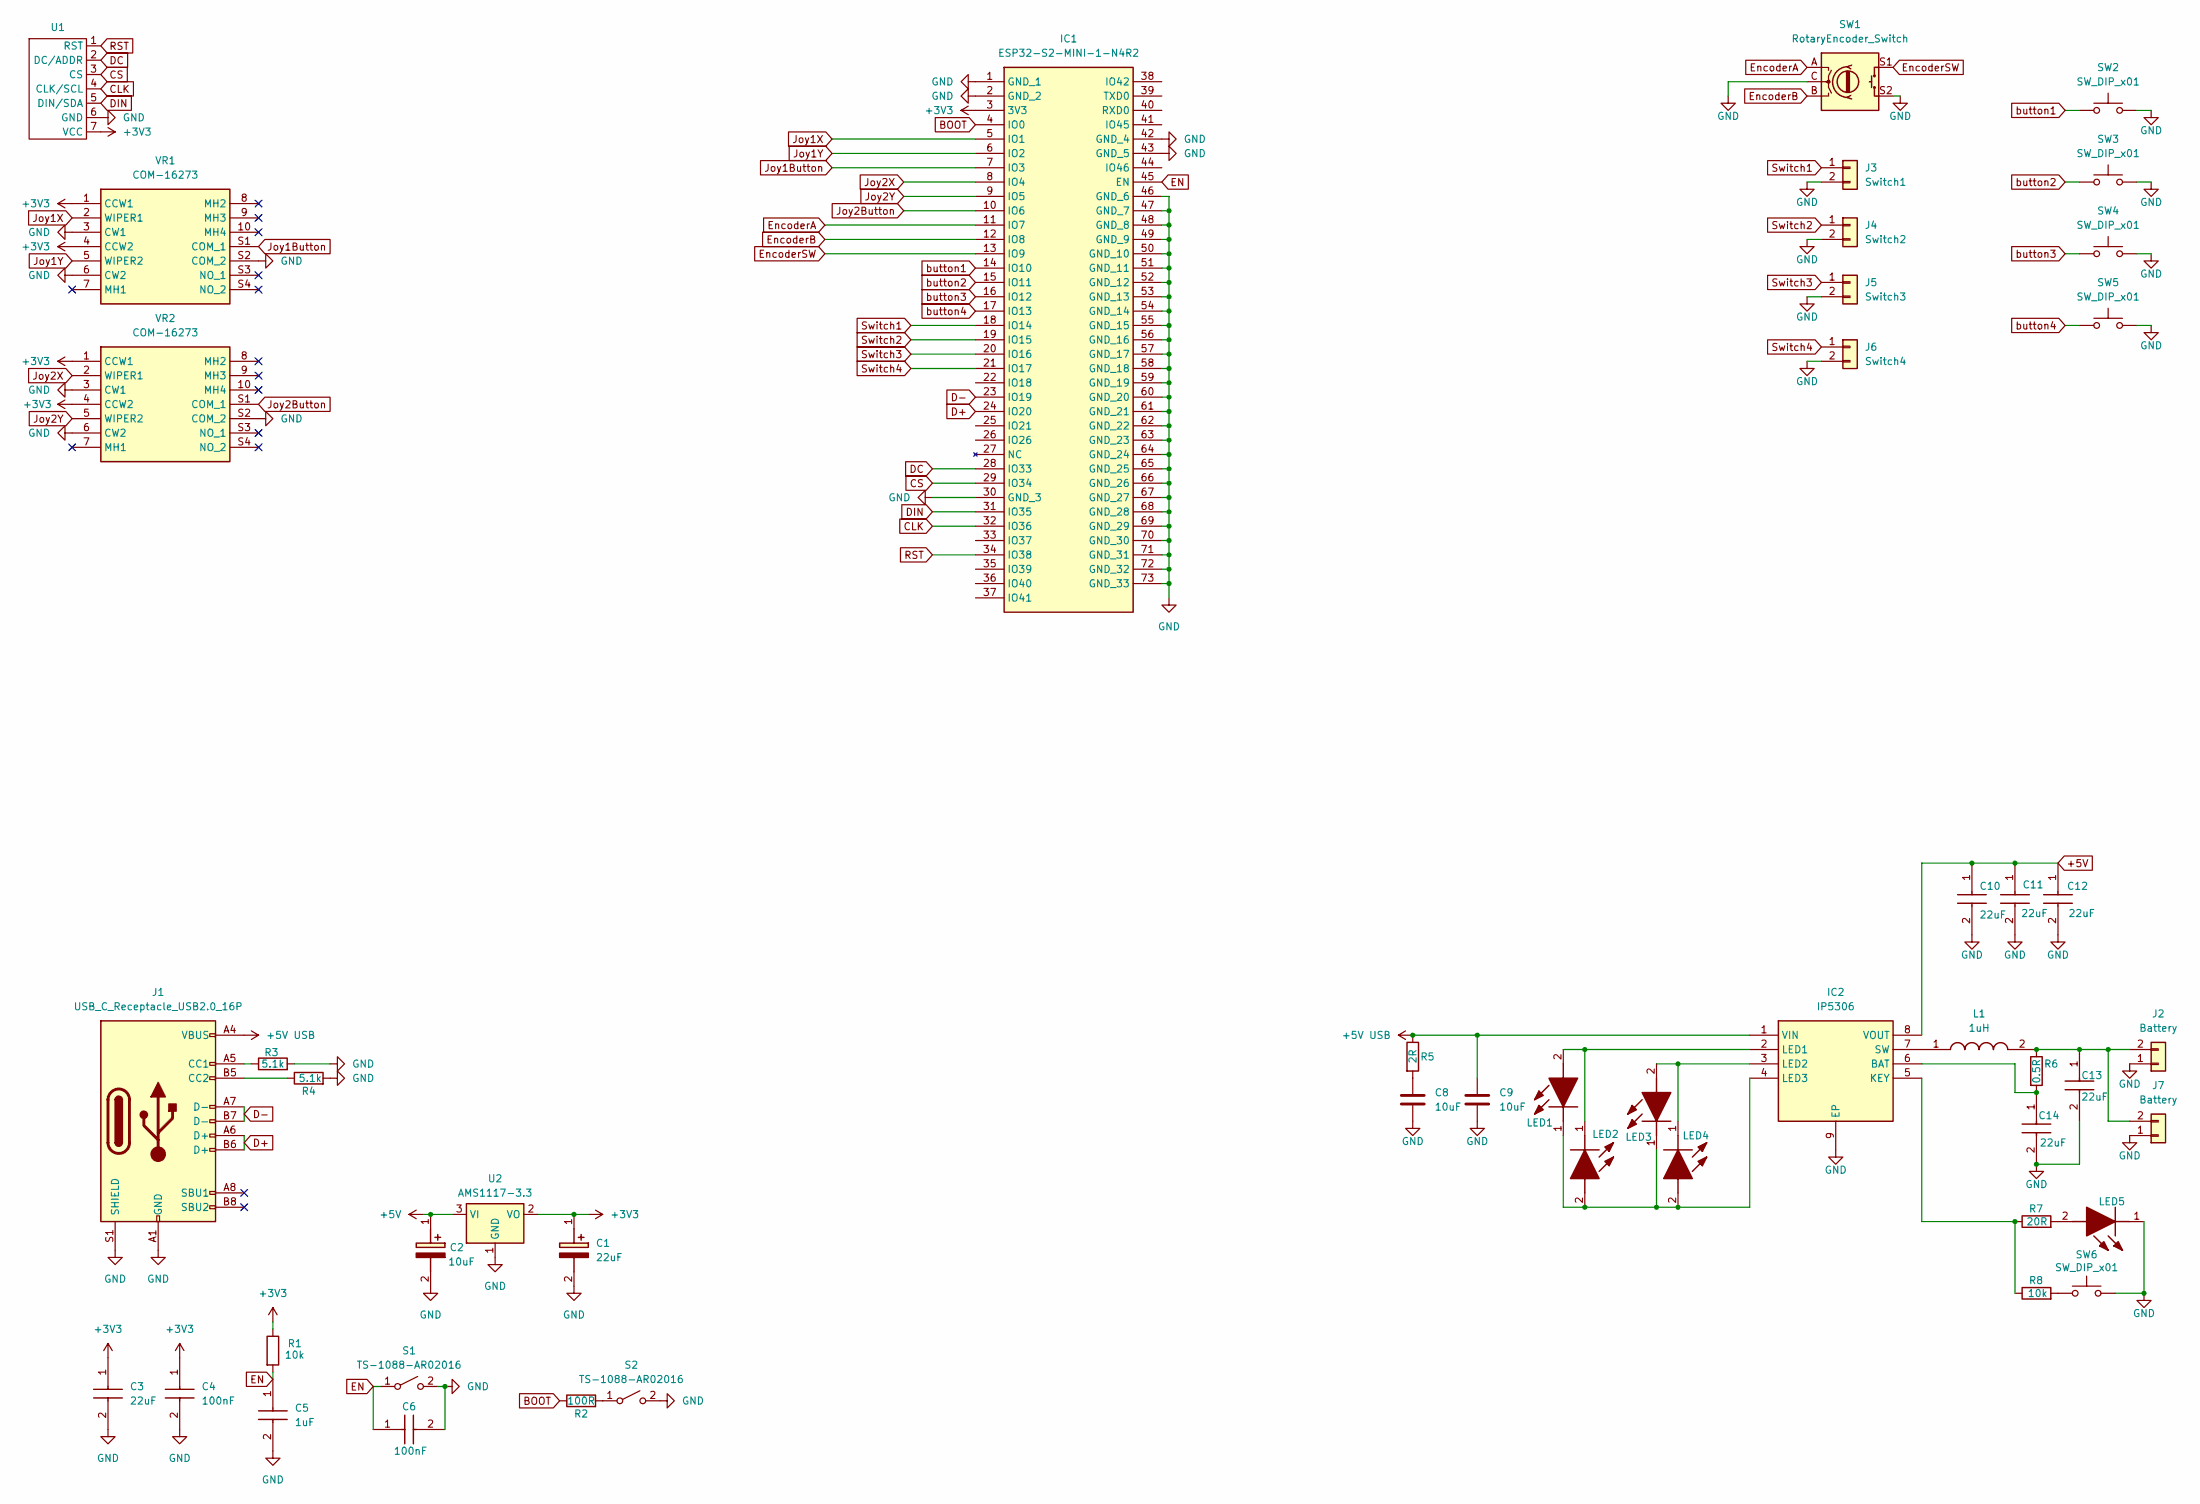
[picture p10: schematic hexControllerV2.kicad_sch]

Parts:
C1: 22uF; CAPPM3528X210N; Manufacturer_Part_Number TCJB226M025R0150E; Mouser Part Number 581-CJB226M025R0150E
C2: 10uF; CAPPM3216X180N; Manufacturer_Part_Number TAJA106K016RNJ; Mouser Part Number 581-TAJA106K016R
C3, C10, C11, C12, C13, C14: 22uF; CAPC2012X140N; Manufacturer_Part_Number CL21A226MAQNNNE; Mouser Part Number 187-CL21A226MAQNNNE
C4, C6: 100nF; CAPC2012X95N; Manufacturer_Part_Number CC0805KRX7R9BB104; Mouser Part Number 603-CC805KRX7R9BB104
C5: 1uF; CAPC2012X135N; Manufacturer_Part_Number CL21B105KBFNNNE; Mouser Part Number 187-CL21B105KBFNNNE
C8, C9: 10uF; C_0805_2012Metric
IC1: ESP32-S2-MINI-1-N4R2; ESP32S2MINI1N4R2; Manufacturer_Part_Number ESP32-S2-MINI-1-N4R2; Mouser Part Number 356-ESP32S2MINI1N4R2
IC2: IP5306; SOIC127P600X165-9N; Manufacturer_Part_Number IP5306
J1: USB_C_Receptacle_USB2.0_16P; USB_C_Receptacle_GCT_USB4105-xx-A_16P_TopMnt_Horizontal
J2, J7: Battery; PinHeader_1x02_P2.54mm_Vertical
J3: Switch1; PinHeader_1x02_P2.54mm_Vertical
J4: Switch2; PinHeader_1x02_P2.54mm_Vertical
J5: Switch3; PinHeader_1x02_P2.54mm_Vertical
J6: Switch4; PinHeader_1x02_P2.54mm_Vertical
L1: 1uH; XAL40XX; Manufacturer_Part_Number XAL4020-102MEC; Mouser Part Number 994-XAL4020-102MEC
LED1, LED2, LED3, LED4, LED5: KP1608SURCK; Manufacturer_Part_Number KP-1608SURCK; Mouser Part Number N/A
R1, R8: 10k; R_0805_2012Metric
R2: 100R; R_0805_2012Metric
R3, R4: 5.1k; R_0805_2012Metric
R5: 2R; R_0805_2012Metric
R6: 0.5R; R_0805_2012Metric
R7: 20R; R_0805_2012Metric
S1, S2: TS-1088-AR02016; TS1088AR02016; Manufacturer_Part_Number TS-1088-AR02016
SW1: RotaryEncoder_Switch; PEC11L4120FS0020
SW2, SW3, SW4, SW5, SW6: SW_DIP_x01; DTS62NV
U1: WaveShare_2.42inch_SSD1309_OLED
U2: AMS1117-3.3; SOT-223-3_TabPin2
VR1, VR2: COM-16273; COM16273; Mouser Part Number 474-COM-16273

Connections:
+3V3: C1.1 (+), C3.1, C4.1, IC1.3 (3V3), R1.1, U1.7 (VCC), U2.2 (VO), VR1.1 (CCW1), VR1.4 (CCW2), VR2.1 (CCW1), VR2.4 (CCW2)
+5V: C2.1 (+), C10.1, C11.1, C12.1, IC2.8 (VOUT), U2.3 (VI)
+5V USB: C9.1, IC2.1 (VIN), J1.A4 (VBUS), J1.A9 (VBUS), J1.B4 (VBUS), J1.B9 (VBUS), R5.1
BOOT: IC1.4 (IO0), R2.1
CLK: IC1.32 (IO36), U1.4 (CLK/SCL)
CS: IC1.29 (IO34), U1.3 (CS)
D+: IC1.24 (IO20), J1.A6 (D+), J1.B6 (D+)
D-: IC1.23 (IO19), J1.A7 (D-), J1.B7 (D-)
DC: IC1.28 (IO33), U1.2 (DC/ADDR)
DIN: IC1.31 (IO35), U1.5 (DIN/SDA)
EN: C5.1, C6.1, IC1.45 (EN), R1.2, S1.1 (A)
EncoderA: IC1.11 (IO7), SW1.A
EncoderB: IC1.12 (IO8), SW1.B
EncoderSW: IC1.13 (IO9), SW1.S1
GND: C1.2 (-), C2.2 (-), C3.2, C4.2, C5.2, C6.2, C8.2, C9.2, C10.2, C11.2, C12.2, C13.2, C14.2, IC1.1 (GND_1), IC1.2 (GND_2), IC1.30 (GND_3), IC1.42 (GND_4), IC1.43 (GND_5), IC1.46 (GND_6), IC1.47 (GND_7), IC1.48 (GND_8), IC1.49 (GND_9), IC1.50 (GND_10), IC1.51 (GND_11), IC1.52 (GND_12), IC1.53 (GND_13), IC1.54 (GND_14), IC1.55 (GND_15), IC1.56 (GND_16), IC1.57 (GND_17), IC1.58 (GND_18), IC1.59 (GND_19), IC1.60 (GND_20), IC1.61 (GND_21), IC1.62 (GND_22), IC1.63 (GND_23), IC1.64 (GND_24), IC1.65 (GND_25), IC1.66 (GND_26), IC1.67 (GND_27), IC1.68 (GND_28), IC1.69 (GND_29), IC1.70 (GND_30), IC1.71 (GND_31), IC1.72 (GND_32), IC1.73 (GND_33), IC2.9 (EP), J1.A1 (GND), J1.A12 (GND), J1.B1 (GND), J1.B12 (GND), J1.S1 (SHIELD), J2.1, J3.2, J4.2, J5.2, J6.2, J7.1, LED5.1 (K), R3.2, R4.2, S1.2 (B), S2.2 (B), SW1.C, SW1.S2, SW2.2, SW3.2, SW4.2, SW5.2, SW6.2, U1.6 (GND), U2.1 (GND), VR1.3 (CW1), VR1.6 (CW2), VR1.S2 (COM_2), VR2.3 (CW1), VR2.6 (CW2), VR2.S2 (COM_2)
Joy1Button: IC1.7 (IO3), VR1.S1 (COM_1)
Joy1X: IC1.5 (IO1), VR1.2 (WIPER1)
Joy1Y: IC1.6 (IO2), VR1.5 (WIPER2)
Joy2Button: IC1.10 (IO6), VR2.S1 (COM_1)
Joy2X: IC1.8 (IO4), VR2.2 (WIPER1)
Joy2Y: IC1.9 (IO5), VR2.5 (WIPER2)
unnamed: C8.1, R5.2
unnamed: C14.1, IC2.6 (BAT), R6.2
unnamed: IC2.5 (KEY), R7.1, R8.1
unnamed: IC2.2 (LED1), LED1.2 (A), LED2.1 (K)
unnamed: IC2.3 (LED2), LED3.2 (A), LED4.1 (K)
unnamed: IC2.4 (LED3), LED1.1 (K), LED2.2 (A), LED3.1 (K), LED4.2 (A)
unnamed: IC2.7 (SW), L1.1
unnamed: J1.A5 (CC1), R3.1
unnamed: J1.B5 (CC2), R4.1
unnamed: C13.1, J2.2, J7.2, L1.2, R6.1
unnamed: LED5.2 (A), R7.2
unnamed: R8.2, SW6.1
unnamed: R2.2, S2.1 (A)
RST: IC1.34 (IO38), U1.1 (RST)
Switch1: IC1.18 (IO14), J3.1
Switch2: IC1.19 (IO15), J4.1
Switch3: IC1.20 (IO16), J5.1
Switch4: IC1.21 (IO17), J6.1
button1: IC1.14 (IO10), SW2.1
button2: IC1.15 (IO11), SW3.1
button3: IC1.16 (IO12), SW4.1
button4: IC1.17 (IO13), SW5.1

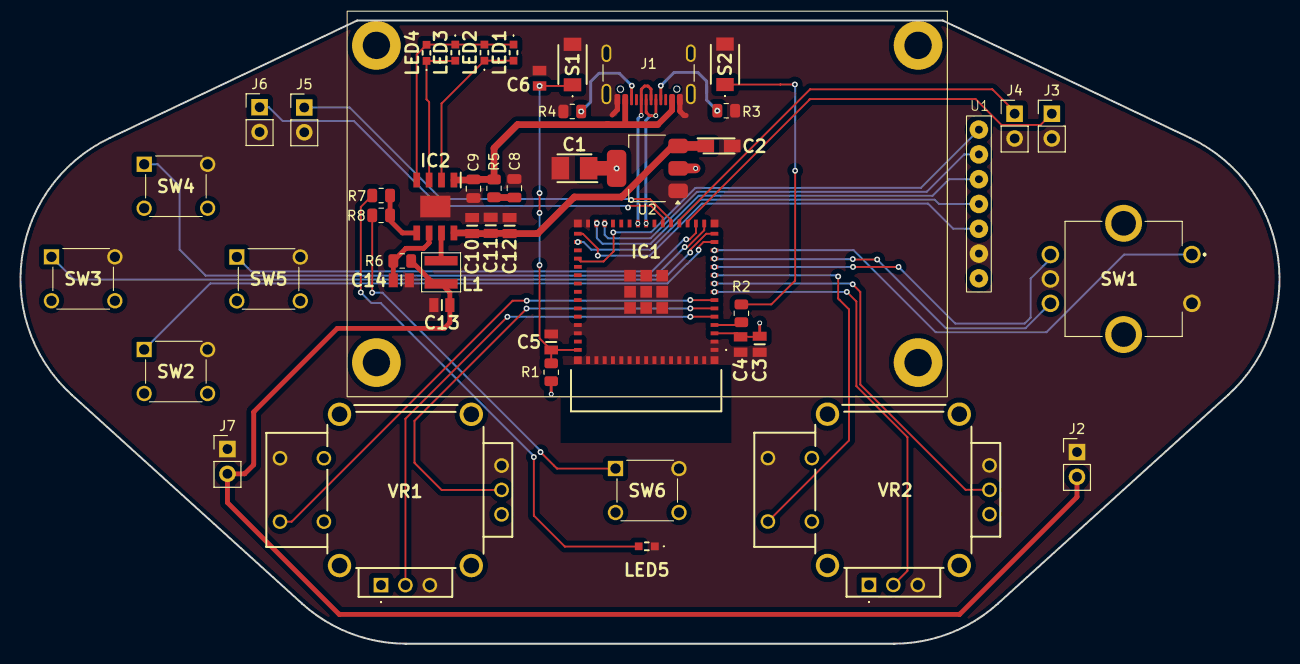
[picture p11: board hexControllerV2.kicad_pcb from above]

Board: 4 copper layers, 129.0 x 63.9 mm, 48 parts (0 on the bottom side), 43 nets.

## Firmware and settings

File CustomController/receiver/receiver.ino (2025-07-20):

#include <WiFi.h>
#include <esp_now.h>
#include <Wire.h>

// Define esp32 I2C slave address
#define I2C_SLAVE_ADDR 0x08

// Mac address for hexapod esp32
uint8_t controllerMAC[] = {0x80, 0x65, 0x99, 0xE9, 0x6F, 0x56};

// Enum for availble commands
enum Command : uint8_t {
  CMD_NONE = 0,
  CMD_SET_GAIT,
  CMD_SET_MODE,
  CMD_SET_CONFIG,
  CMD_HOME_STANCE,
  CMD_REQUEST_CONFIG
};

// Define the data structure with no padding
#pragma pack(push, 1)
// Define ControlPacket struct
struct ControlPacket {
  int16_t joystick1X;
  int16_t joystick1Y;
  int16_t currentHeight;
  Command command;
  int16_t commandArgs[3];
};

// Define HexPacket struct
struct HexPacket {
  int16_t legConfigs[3];
  int16_t currentHeight;
};
#pragma pack(pop)

// Instances of packets
ControlPacket controlPacket = {};
HexPacket hexPacket = {};

//_______________________________________________________________________OnDataRecv__________________________________________________________________

// Function to handle espNOW receive event
void receiveEventEspNOW(const esp_now_recv_info_t *recv_info, const uint8_t *data, int len) {
  if (len != sizeof(ControlPacket)) {
    Serial.println("Invalid packet size");
    return;
  }

  // Temporary holder for the incoming packet
  ControlPacket incomingPacket;
  memcpy(&incomingPacket, data, sizeof(ControlPacket));
  
  if (packetChanged(incomingPacket, controlPacket)) {controlPacket = incomingPacket;}

  esp_now_send(controllerMAC, (uint8_t*)&hexPacket, sizeof(HexPacket));
}

//_______________________________________________________________________requestEvent__________________________________________________________________

// Function to handle I2C request event
void requestEventI2C() {
  // Send the data structure to the master (Raspberry Pi Pico)
  Wire.write((uint8_t*)&controlPacket, sizeof(ControlPacket));
}

//_______________________________________________________________________receiveEvent__________________________________________________________________

// Function to handle I2C receive event (ESP32 receives updated HexPacket from Pico)
void receiveEventI2C(int numBytes) {
  if (numBytes != sizeof(HexPacket)) {
    Serial.printf("Warning: Expected %d bytes, received %d\n", sizeof(HexPacket), numBytes);
  }

  Wire.readBytes((char*)&hexPacket, sizeof(HexPacket));
}

//_______________________________________________________________________packetChanged__________________________________________________________________

// Compare if two ControlPackets are different
bool packetChanged(const ControlPacket& a, const ControlPacket& b) {
  if (a.joystick1X != b.joystick1X) return true;
  if (a.joystick1Y != b.joystick1Y) return true;
  if (a.currentHeight != b.currentHeight) return true;
  if (a.command != b.command) return true;

  for (int i = 0; i < 3; i++) {
    if (a.commandArgs[i] != b.commandArgs[i]) return true;
  }
  return false;
}


//_______________________________________________________________________setup__________________________________________________________________
void setup() {
  Serial.begin(115200);
  WiFi.mode(WIFI_STA);
  esp_now_init();

  esp_now_peer_info_t peerInfo = {};
  memcpy(peerInfo.peer_addr, controllerMAC, 6);
  peerInfo.channel = 0;
  peerInfo.encrypt = false;
  if (!esp_now_is_peer_exist(controllerMAC)) {esp_now_add_peer(&peerInfo);}

  esp_now_register_recv_cb(receiveEventEspNOW); // Set callback function to handle espNOW receive event
  Wire.begin(I2C_SLAVE_ADDR); // Initialize I2C as slave with specified address
  Wire.onRequest(requestEventI2C); // Set callback function to handle I2C request event
  Wire.onReceive(receiveEventI2C); // Set callback function to handle I2C receive event
}

//_______________________________________________________________________loop__________________________________________________________________
void loop() {
  // Do nothing
}

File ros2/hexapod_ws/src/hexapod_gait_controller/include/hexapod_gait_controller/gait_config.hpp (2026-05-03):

#ifndef HEXAPOD_GAIT_CONTROLLER_GAIT_CONFIG_HPP
#define HEXAPOD_GAIT_CONTROLLER_GAIT_CONFIG_HPP

#include <cstdint>
#include <Eigen/Dense>
#include <map>

using Eigen::Vector3d;
using Eigen::AngleAxisd;
using Eigen::Matrix3d;

namespace hexapod_gait_controller {

static constexpr int MAX_LEGS = 6;
static constexpr int MAX_RESOLUTION = 50;
static const double MAX_LINEAR_VELOCITY = 0.2; // m/s
static const double MAX_STRIDE_LENGTH = 0.06; // m
static const double MAX_ANGULAR_VELOCITY = 2.0; // rad/s
static const double LIFT_HEIGHT = 0.05;

struct LocomotionOption {
    std::string name;
    uint8_t id;
};

enum Gait : uint8_t {
    GAIT_TRIPOD,
    GAIT_RIPPLE,
    GAIT_WAVE,
    NUM_GAITS
};

enum Mode : uint8_t {
    MODE_NORMAL,
    MODE_STRAFE,
    MODE_TILT,
    MODE_CONFIG,
    NUM_MODES
};

class GaitConfig {
private:
    const std::vector<LocomotionOption> gaits = {
        {"tripod", GAIT_TRIPOD},
        {"ripple", GAIT_RIPPLE},
        {"wave", GAIT_WAVE}
    };
    const std::vector<LocomotionOption> modes = {
        {"normal", MODE_NORMAL},
        {"strafe", MODE_STRAFE},
        {"tilt", MODE_TILT},
        {"config", MODE_CONFIG}
    };
    Vector3d rotateZ(const Vector3d& v, double degrees);
public:
    const std::vector<LocomotionOption>& getGaits() const { return gaits; }
    const std::vector<LocomotionOption>& getModes() const { return modes; }
    double currentHeight = -0.12;
    Vector3d homePos {0.15, 0, 0};
    Vector3d startPos {0.15, 0, currentHeight};
    std::map<int, Vector3d> startPosition{
        {1, rotateZ(startPos, 15)},
        {2, startPos},
        {3, rotateZ(startPos, -15)},
        {4, rotateZ(startPos, 15)},
        {5, startPos},
        {6, rotateZ(startPos, -15)}
    };
    Gait currentGait = GAIT_TRIPOD;
    Mode currentMode = MODE_NORMAL;
    bool gaitChangeRequested = false;
    Gait pendingGait;
    std::vector<std::vector<int>> getGaitConfig(Gait gait);
    void cycleGait();
    void setGait(Gait gait);
    void cycleMode();
    void setMode(Mode mode);
    void setHeight(double height);
};

}  // namespace hexapod_gait_controller

#endif // HEXAPOD_GAIT_CONTROLLER_GAIT_CONFIG_HPP

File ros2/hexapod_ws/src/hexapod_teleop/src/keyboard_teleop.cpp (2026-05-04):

#include "rclcpp/rclcpp.hpp"
#include "geometry_msgs/msg/twist.hpp"
#include "hexapod_interfaces/srv/get_capabilities.hpp"
#include "hexapod_interfaces/msg/locomotion_option.hpp"
#include "hexapod_interfaces/srv/set_mode.hpp"
#include "hexapod_interfaces/srv/set_gait.hpp"

#include <iostream>
#include <sys/select.h>
#include <termios.h>
#include <unistd.h>

using geometry_msgs::msg::Twist;
using hexapod_interfaces::srv::GetCapabilities;
using hexapod_interfaces::srv::SetMode;
using hexapod_interfaces::srv::SetGait;

class KeyboardTeleop : public rclcpp::Node {public: KeyboardTeleop() : Node("keyboard_teleop") {
  	RCLCPP_INFO(this->get_logger(), "Keyboard Teleop Node has been started.");
  	cmd_vel_pub = this->create_publisher<Twist>("cmd_vel", 10);
  	get_capabilities_client = this->create_client<GetCapabilities>("get_capabilities");
	set_mode_client = this->create_client<SetMode>("set_mode");
	set_gait_client = this->create_client<SetGait>("set_gait");

	fetchCapabilities();
}
private:
  	rclcpp::Publisher<Twist>::SharedPtr cmd_vel_pub;
  	rclcpp::Client<GetCapabilities>::SharedPtr get_capabilities_client;
	rclcpp::Client<SetMode>::SharedPtr set_mode_client;
	rclcpp::Client<SetGait>::SharedPtr set_gait_client;
	std::vector<hexapod_interfaces::msg::LocomotionOption> available_gaits;
	std::vector<hexapod_interfaces::msg::LocomotionOption> available_modes;
	size_t current_gait_index = 0;
	size_t current_mode_index = 0;
  	double linearX = 0;
  	double linearY = 0;
  	double angularZ = 0;
  	termios orig_termios_{};
  	bool termios_ready_ = false;
public:
  	void userInputLoop();
  	void enableRawMode();
  	void disableRawMode();
  	int readKeyWithTimeout(int timeout_ms);
  	void fetchCapabilities();
};

int main(int argc, char * argv[]) {
	rclcpp::init(argc, argv);
	auto node = std::make_shared<KeyboardTeleop>();
	node->userInputLoop();
	rclcpp::spin(node);
	rclcpp::shutdown();
	return 0;
}

void KeyboardTeleop::fetchCapabilities() {
    if (!get_capabilities_client->wait_for_service(std::chrono::seconds(2))) {
        RCLCPP_WARN(this->get_logger(), "GetCapabilities service not available");
        return;
    }

    auto request = std::make_shared<hexapod_interfaces::srv::GetCapabilities::Request>();
    auto result_future = get_capabilities_client->async_send_request(request);

    // Wait for the result (synchronously for simplicity)
    if (rclcpp::spin_until_future_complete(this->get_node_base_interface(), result_future) ==
        rclcpp::FutureReturnCode::SUCCESS)
    {
        auto response = result_future.get();

		available_gaits = response->gaits;
		available_modes = response->modes;

		RCLCPP_INFO(this->get_logger(), "Received capabilities: %zu gaits, %zu modes",
					available_gaits.size(), available_modes.size());
    } else {
        RCLCPP_ERROR(this->get_logger(), "Failed to call GetCapabilities service");
    }
}

void KeyboardTeleop::userInputLoop() {
	enableRawMode();
	RCLCPP_INFO(this->get_logger(), "\nControls:\n Linear:	[w/s/a/d]\n Angular:	[e/q]\n stop:		[x]\n Gait:		[g]\n Mode:		[m]\n Exit:		[c]\n");
	while (rclcpp::ok()) {
		int key = readKeyWithTimeout(50);
		if (key < 0) {
		continue;
		}

    Twist cmd_vel_msg;
    if (key == 'w') {
        linearX += 0.01;
        RCLCPP_INFO(this->get_logger(), "Increasing linear X: %.2f", linearX);
    } else if (key == 's') {
        linearX -= 0.01;
        RCLCPP_INFO(this->get_logger(), "Decreasing linear X: %.2f", linearX);
    } else if (key == 'a') {
        linearY += 0.01;
        RCLCPP_INFO(this->get_logger(), "Increasing linear Y: %.2f", linearY);
    } else if (key == 'd') {
        linearY -= 0.01;
        RCLCPP_INFO(this->get_logger(), "Decreasing linear Y: %.2f", linearY);
    } else if (key == 'e') {
        angularZ -= 0.1;
        RCLCPP_INFO(this->get_logger(), "Increasing angular Z: %.2f", angularZ);
    } else if (key == 'q') {
        angularZ += 0.1;
        RCLCPP_INFO(this->get_logger(), "Decreasing angular Z: %.2f", angularZ);
    } else if (key == 'x') {
        linearX = 0;
        linearY = 0;
        angularZ = 0;
        RCLCPP_INFO(this->get_logger(), "Stopping robot");
	} else if (key == 'g') {
		if (!available_gaits.empty()) {
			current_gait_index = (current_gait_index + 1) % available_gaits.size();
			const auto& gait = available_gaits[current_gait_index];
			auto request = std::make_shared<SetGait::Request>();
			request->gait = gait.id;
			auto result_future = set_gait_client->async_send_request(request);
			if (rclcpp::spin_until_future_complete(this->get_node_base_interface(), result_future) ==
				rclcpp::FutureReturnCode::SUCCESS)
			{
				auto response = result_future.get();
				if (response->success) {
					RCLCPP_INFO(this->get_logger(), "Selected gait: [%d] %s", gait.id, gait.name.c_str());
				} else {
					RCLCPP_WARN(this->get_logger(), "Failed to set gait");
				}
			} else {
				RCLCPP_ERROR(this->get_logger(), "Failed to call SetGait service");
			}
		}
	} else if (key == 'm') {
		if (!available_modes.empty()) {
			current_mode_index = (current_mode_index + 1) % available_modes.size();
			const auto& mode = available_modes[current_mode_index];
			auto request = std::make_shared<SetMode::Request>();
			request->mode = mode.id;
			auto result_future = set_mode_client->async_send_request(request);
			if (rclcpp::spin_until_future_complete(this->get_node_base_interface(), result_future) ==
				rclcpp::FutureReturnCode::SUCCESS)
			{
				auto response = result_future.get();
				if (response->success) {
					RCLCPP_INFO(this->get_logger(), "Selected mode: [%d] %s", mode.id, mode.name.c_str());
				} else {
					RCLCPP_WARN(this->get_logger(), "Failed to set mode");
				}
			} else {
				RCLCPP_ERROR(this->get_logger(), "Failed to call SetMode service");
			}
		}
    } else if (key == 'c') {
        RCLCPP_INFO(this->get_logger(), "Exiting...");
        break;
    } else {
        continue;
    }

    cmd_vel_msg.linear.x = linearX;
    cmd_vel_msg.linear.y = linearY;
    cmd_vel_msg.angular.z = angularZ;

    cmd_vel_pub->publish(cmd_vel_msg);
  	}

  	disableRawMode();
}

void KeyboardTeleop::enableRawMode() {
	if (termios_ready_) {
		return;
	}
	if (tcgetattr(STDIN_FILENO, &orig_termios_) == -1) {
		RCLCPP_ERROR(this->get_logger(), "Failed to get terminal attributes");
		return;
	}
	termios raw = orig_termios_;
	raw.c_lflag &= static_cast<unsigned>(~(ECHO | ICANON));
	raw.c_cc[VMIN] = 0;
	raw.c_cc[VTIME] = 0;
	if (tcsetattr(STDIN_FILENO, TCSANOW, &raw) == -1) {
		RCLCPP_ERROR(this->get_logger(), "Failed to set terminal raw mode");
		return;
	}
	termios_ready_ = true;
}

void KeyboardTeleop::disableRawMode() {
	if (!termios_ready_) {return;}
	tcsetattr(STDIN_FILENO, TCSANOW, &orig_termios_);
	termios_ready_ = false;
}
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

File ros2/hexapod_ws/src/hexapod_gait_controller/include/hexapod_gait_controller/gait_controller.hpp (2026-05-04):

#ifndef HEXAPOD_GAIT_CONTROLLER_GAIT_CONTROLLER_HPP
#define HEXAPOD_GAIT_CONTROLLER_GAIT_CONTROLLER_HPP

#include "rclcpp/rclcpp.hpp"
#include "hexapod_gait_controller/trajectory_generator.hpp"
#include "hexapod_gait_controller/kinematic_solver.hpp"
#include "hexapod_gait_controller/gait_config.hpp"
#include "geometry_msgs/msg/twist.hpp"
#include "sensor_msgs/msg/joint_state.hpp"
#include "hexapod_interfaces/srv/set_gait.hpp"
#include "hexapod_interfaces/srv/set_mode.hpp"
#include "hexapod_interfaces/srv/set_height.hpp"
#include "hexapod_interfaces/srv/get_capabilities.hpp"
#include "hexapod_interfaces/msg/locomotion_option.hpp"

using namespace hexapod_gait_controller;

using geometry_msgs::msg::Twist;
using sensor_msgs::msg::JointState;
using hexapod_interfaces::srv::SetGait;
using hexapod_interfaces::srv::SetMode;
using hexapod_interfaces::srv::SetHeight;
using hexapod_interfaces::srv::GetCapabilities;
using Eigen::Vector3d;
using std::placeholders::_1;
using std::placeholders::_2;

struct MotionIntent {
    double forward;
    double lateral;
    double yaw;
};

class GaitController : public rclcpp::Node { 
public: 
    GaitController() : Node("gait_controller") {
        cmd_vel_sub = this->create_subscription<Twist>("cmd_vel", 10, std::bind(&GaitController::cmdVelCallback, this, _1));
        joint_state_sub = this->create_subscription<JointState>("joint_states", 10, std::bind(&GaitController::jointStateCallback, this, _1));

        joint_cmd_pub = this->create_publisher<JointState>("joint_commands", 10);

        set_gait_service = this->create_service<SetGait>("set_gait", std::bind(&GaitController::setGaitCallback, this, _1, _2));
        set_mode_service = this->create_service<SetMode>("set_mode", std::bind(&GaitController::setModeCallback, this, _1, _2));
        set_height_service = this->create_service<SetHeight>("set_height", std::bind(&GaitController::setHeightCallback, this, _1, _2));
        get_capabilities_service = this->create_service<GetCapabilities>("get_capabilities", std::bind(&GaitController::getCapabilitiesCallback, this, _1, _2));
        
        double loop_rate_hz = 50.0;
        gait_timer = this->create_wall_timer(std::chrono::duration<double>(1.0 / loop_rate_hz), std::bind(&GaitController::gaitTimerCallback, this));

        RCLCPP_INFO(this->get_logger(), "GaitController node started at %.1f Hz", loop_rate_hz);
    }    
private:
    rclcpp::Subscription<Twist>::SharedPtr cmd_vel_sub;
    rclcpp::Publisher<JointState>::SharedPtr joint_cmd_pub;
    rclcpp::Subscription<JointState>::SharedPtr joint_state_sub;
    rclcpp::TimerBase::SharedPtr gait_timer;
    rclcpp::Service<SetGait>::SharedPtr set_gait_service;
    rclcpp::Service<SetMode>::SharedPtr set_mode_service;
    rclcpp::Service<SetHeight>::SharedPtr set_height_service;
    rclcpp::Service<GetCapabilities>::SharedPtr get_capabilities_service;
    TrajectoryGenerator trajectoryGen;
    GaitConfig gaitConfig;
    KinematicSolver ikSolver;
    
    uint8_t step = 0;
    uint8_t phase = 0;
    uint8_t startup_step = 0;
    
    Twist last_cmd_vel;
    Twist filtered_cmd_vel;
    Twist trajectory_cmd_vel;
    JointState latest_joint_states;
    MotionIntent current_motion_intent{};
    MotionIntent trajectory_motion_intent{};
    
    bool has_joint_states = false;
    bool positions_initialized = false;
    bool idleReturning = false;
    
    static constexpr double CMD_VEL_CHANGE_THRESHOLD = 0.05;

    std::array<std::array<Vector3d, MAX_RESOLUTION + 1>, MAX_LEGS + 1> startup_trajectory;
    std::array<Vector3d, MAX_LEGS + 1> current_leg_positions;
    std::array<int, MAX_LEGS + 1> startup_sizes{};
    
public:
    void cmdVelCallback(const Twist::SharedPtr msg);
    void jointStateCallback(const JointState::SharedPtr msg);
    void setGaitCallback(const std::shared_ptr<SetGait::Request> request, std::shared_ptr<SetGait::Response> response);
    void setModeCallback(const std::shared_ptr<SetMode::Request> request, std::shared_ptr<SetMode::Response> response);
    void setHeightCallback(const std::shared_ptr<SetHeight::Request> request, std::shared_ptr<SetHeight::Response> response);
    void getCapabilitiesCallback(const std::shared_ptr<GetCapabilities::Request> request, std::shared_ptr<GetCapabilities::Response> response);
    void gaitTimerCallback();
    void appendJointCommand(JointState& joint_state_msg, const Vector3d& target, int legNum);
    void sendJointcommands(JointState& msg);
    void home();
    void startup();
    void PerformLegStep(bool idle, bool handlePhaseTransition = true);
    void returnToStart();
    bool HandleIdleReturn();
    void walk();
};

#endif // HEXAPOD_GAIT_CONTROLLER_GAIT_CONTROLLER_HPP

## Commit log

2024-06-14 Created "GetLegConfig" function in "Move" class
    The "GetLegConfig" function returns a leg configuration based on a given gait
    Moved the leg map to header private
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2024-06-27 Added method of selecting Modes
    mode enum to contain various modes
    CycleMode function to change mode to next mode in the enum
    SetMode to set current mode to desired mode
2024-07-08 Added method of recording leg position
    Created unordered map that stores position with leg number as key
    Created GetLegPosition that returns current leg position
2024-07-09 Added ability to use use and read switches on leg tips
    Added "SetupSwitches" function to initialize switches with pulldown resistors
    Added "GetSwitchStatus" function that returns switch state
    Created a map which maps switch to correct leg
    Added a constructor to call switch setup on object creation
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2024-07-29 Changed inverse kinematics to account for leg angular offset
    Leg configuration stored in a map initialized by a constructor
    Altered Move.cpp to include the leg number when calling the calculate angle function
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2025-06-26 Fixed encoder interpreter
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2025-07-02 Fixed bug where item_selected was reset before switching states
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2025-07-18 Fixed bug when assigning negative leg offsets
2025-07-18 Reworked data transfer through receiver
    [receiver.ino]
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2025-07-21 Reworked controller code using PlatformIO
    [main.cpp]
2025-07-21 Fixed indentation in main.cpp and removed unused files
    [main.cpp]
2025-07-21 Reworked receiver code using platformIO
    [main.cpp, receiver.ino]
2025-07-21 Correct logic errors in initialization and data handling
    [main.cpp]
2025-07-23 Added method to convert leg positions to body frame based on leg configuration.
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2025-07-24 Added new struct LegPosition to hold both position and angles for each leg.
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2025-07-24 Replaced Joint() with Angles() in move class to set leg angles directly.
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2025-07-28 Added controller schematic
    [hexControllerV2-B_Cu.gbr, hexControllerV2-B_Mask.gbr, hexControllerV2-B_Paste.gbr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]
2025-07-28 Reworking schematic
    [hexControllerV2.kicad_pcb, hexControllerV2.kicad_sch, hexControllerV2.step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]
2025-07-28 Improved PCB design
    [hexControllerV2.step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]
2025-07-29 Changed schematic/ PCB
    [hexControllerV3-B_Cu.gbr, hexControllerV3-B_Mask.gbr, hexControllerV3-B_Paste.gbr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]
2025-08-22 Altered controller schematic
    [hexControllerV3.kicad_pcb, hexControllerV3.kicad_sch, hexControllerV3.step]
2025-08-27 Corrected pin config for schematic
    [hexControllerV3.kicad_pcb, hexControllerV3.kicad_sch]
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2025-08-27 Fixed forward kinematic equations
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2025-09-02 Reworked Calculate class for ESP32-S3 compatibility
2025-09-02 Reworked DataPacket files for ESP32-S3 compatibility
2025-09-02 Reworked ConfigManager class for ESP32-S3 compatibility
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2025-09-02 Reworked Move class for ESP32-S3 compatibility
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2025-09-02 Reorganized controller files
    [hexControllerV2-B_Cu.gbr, hexControllerV2-B_Mask.gbr, hexControllerV2-B_Paste.gbr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]
2025-09-02 Reverted back to Controller managing data timing
    [hexControllerV2-B_Cu.gbr, hexControllerV2-B_Mask.gbr, hexControllerV2-B_Paste.gbr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]
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2025-09-03 Refactor LegContactSensor to use static const LEG_SENSORS array for GPIO pin management
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2025-09-03 Add ESP32-S3 BOM spreadsheet for component tracking
    [ESP32-S3_BOM.xlsx]
2025-09-03 Update ESP32-S3 BOM spreadsheet for component tracking
    [ESP32-S3_BOM.xlsx]
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2025-09-03 Refactor CurrentSensor class to remove Adafruit_INA260 dependency and implement register-based reading methods
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2025-09-03 Update BOM file for Hexapod project
    [ESP32-S3_BOM.xlsx]
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2025-09-05 Update I2CManager methods to return boolean status for write and read operations
2025-09-05 Implement read and write register methods in I2CManager for enhanced I2C communication
2025-09-05 Refactor CurrentSensor to remove readRegister method and use I2CManager for register reads
2025-09-05 Refactor IMUSensor to remove direct register read/write methods and utilize I2CManager for improved I2C communication and error handling
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2025-09-05 Refactor I2CManager to support configurable I2C port in init method and update related methods
2025-09-05 Refactor Move class by removing unused switch setup methods and current draw logic for cleaner code
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2025-09-08 added items to BOM
    [ESP32-S3_BOM.xlsx]
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2025-09-12 Editted schematic
    [ESP32-S3_BOM.xlsx, Hexapod.kicad_pcb, Hexapod.kicad_sch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]
2025-09-15 Updated controller schematic
    [hexControllerV3.kicad_pcb, hexControllerV3.kicad_sch, hexController_BOM.xlsx]
2025-09-16 Changed schematic
    [hexControllerV3.kicad_pcb, hexControllerV3.kicad_sch, hexController_BOM.xlsx]
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2025-12-13 Initial commit controllerV2 board template
    [code-format.cfg, partitions.csv]
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2025-12-15 Replace menu button event callback with a lambda function for improved readability
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2025-12-16 Reorganised file structure
    [code-format.cfg, hexControllerV2.step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]
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2026-01-15 Enhance uart_receive_loop to log checksum errors with details and assign joystick values to controlPacket based on request_cmd
2026-01-23 Added hexapod_description package
    [hexapod.urdf.xacro]
2026-01-23 organised file structure
    [ESP32-S3_BOM.xlsx, Hexapod.kicad_pcb, Hexapod.kicad_sch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]
2026-01-23 Add RViz configuration and update URDF properties for hexapod model
    [hexapod.urdf.xacro]
2026-01-23 Update coxa dimensions in hexapod URDF for improved leg geometry
    [hexapod.urdf.xacro]
2026-01-23 Fix leg positioning and orientation for rear and front right legs in hexapod URDF
    [hexapod.urdf.xacro]
2026-01-23 Add collision geometry for legs and body in hexapod URDF
    [hexapod.urdf.xacro]
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2026-01-28 Add Gazebo launch file and URDF for hexapod robot simulation
    [hexapod_gazebo.urdf.xacro]
2026-01-28 Update URDF file for hexapod: replace gazebo-specific model with simplified box geometry and add inertial properties; remove obsolete gazebo.urdf.xacro file.
    [hexapod.urdf.xacro, hexapod_gazebo.urdf.xacro]
2026-01-30 Add ROS2 control and transmission definitions for hexapod joints in URDF
    [hexapod.urdf.xacro]
2026-01-30 Refactor Gazebo launch file: replace ExecuteProcess with IncludeLaunchDescription for improved robot spawning and update URDF processing
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2026-01-31 Implement GenerateTrajectories method in TrajectoryGenerator: add functionality for generating swing and stance trajectories with collision checks and body frame conversions
2026-01-31 Refactor TrajectoryGenerator and GaitController: update trajectory generation methods for improved error handling and clarity, replace KinematicSolver with GaitConfig, and enhance frame conversion me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
2026-02-03 Refactor frame conversion methods: implement rotation and translation for leg-to-body and body-to-leg transformations; update ExecuteGait liftHeight parameter to use meters; adjust trajectory collisi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
    [frame_converter.hpp]
2026-02-03 Fix Z-axis calculations in kinematic solver and trajectory generator: negate Z in FK to match IK convention and use fixed ground height to prevent Z drift from FK errors.
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2026-02-03 Refactor GaitController: simplify current leg position retrieval in Strafe and Normal methods to use trajectory endpoints only, eliminating FK feedback to prevent forward drift.
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2026-02-03 Refactor direction method in TrajectoryGenerator: adjust leg angle calculation for non-mirrored leg configurations to ensure correct transformation from body frame to leg frame.
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2026-02-04 Enhance solveIK method in KinematicSolver: add workspace constraints to ensure target positions are within reach, preventing invalid joint angle calculations.
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2026-02-04 Fix default height in GaitConfig: change currentHeight from 0.15 to -0.15 for correct initialization.
    [gait_config.hpp]
2026-02-04 Fix default currentHeight in GaitConfig: change from -0.15 to -0.12 for accurate initialization.
    [gait_config.hpp]
2026-02-06 Update Dockerfile to include CMAKE_EXPORT_COMPILE_COMMANDS in build arguments and add missing header guards in gait_controller.hpp
    [gait_controller.hpp]
2026-02-08 Replace std::cout with RCLCPP_INFO for control instructions in keyboard teleop
    [keyboard_teleop.cpp]
2026-02-09 Refactor gait control methods: replace Strafe and Normal with walk for improved clarity and functionality
    [gait_controller.hpp]
2026-02-17 Fix tibia transmission name typo in URDF file
    [hexapod.urdf.xacro]
2026-03-03 reorganize file structure
    [ESP32-S3_BOM.xlsx, Hexapod.kicad_pcb, Hexapod.kicad_sch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]
2026-03-03 refactor naming convention
    [ESP32-S3_BOM.xlsx, Hexapod.kicad_pcb, Hexapod.kicad_sch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]
2026-03-16 Added meshes to robot URDF
    [hexapod.urdf.xacro]
2026-03-17 Converted meshes to .dae format and included foxglove bridge on robot side
    [hexapod.urdf.xacro]
2026-03-17 Refactor URDF Xacro for Hexapod: Remove unused properties and standardize RPY values
    - Removed mesh orientation correction properties: mesh_up_correction_rpy and mesh_up_correction_with_yaw_rpy.
    - Standardized RPY values for base_link, coxa, femur, and tibia links to use fixed values instead of properties.
    [hexapod.urdf.xacro]
2026-03-17 Update mesh scaling in URDF: change scale from 0.01 to 1 for body, coxa, femur, and tibia
    [hexapod.urdf.xacro]
2026-03-19 Enhance Hexapod control: add joint state relay, update URDF, and configure controllers
    [controllers.yaml, hexapod_primitives.urdf.xacro]
2026-04-25 Update Dockerfile and configuration for Jazzy ROS version; add world file for simulation
    [controllers.yaml, hexapod.urdf.xacro, hexapod_primitives.urdf.xacro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]
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2026-04-25 Add sensors to hexapod URDF: camera, front depth camera, IMU, and lidar
    [hexapod_primitives.urdf.xacro]
2026-04-25 Add indoor house layout and furniture models to hexapod world simulation
    [hexapod_world.sdf]
2026-04-25 Add launch arguments for front depth camera configuration and improve joint state relay QoS
    [hexapod_primitives.urdf.xacro]
2026-04-26 Update depth camera parameters and add PCL filtering nodes in simulation
    [hexapod_primitives.urdf.xacro]
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2026-05-04 Fix angular Z control logic in user input loop for correct movement direction
    [keyboard_teleop.cpp]
2026-05-04 Fix angular Z axis definition in joyCallback for correct rotation control
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
